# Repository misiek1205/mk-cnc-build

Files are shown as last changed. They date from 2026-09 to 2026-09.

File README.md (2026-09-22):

> **Work in progress / early release.** This build pack is actively developed. Parts, fits, docs, and Bambu projects may change; something may not match your leftover hardware yet. Build at your own risk and expect updates.

# MK CNC — scavenger gantry mill (build pack)

**Work envelope (nominal):** X **299** × Y **271** × Z **100** mm  
**Stack:** printed PLA / PETG / ASA parts + 2020 aluminium extrusion + MGN12 + T8 leadscrews + NEMA steppers (mostly recycled from 3D printers)

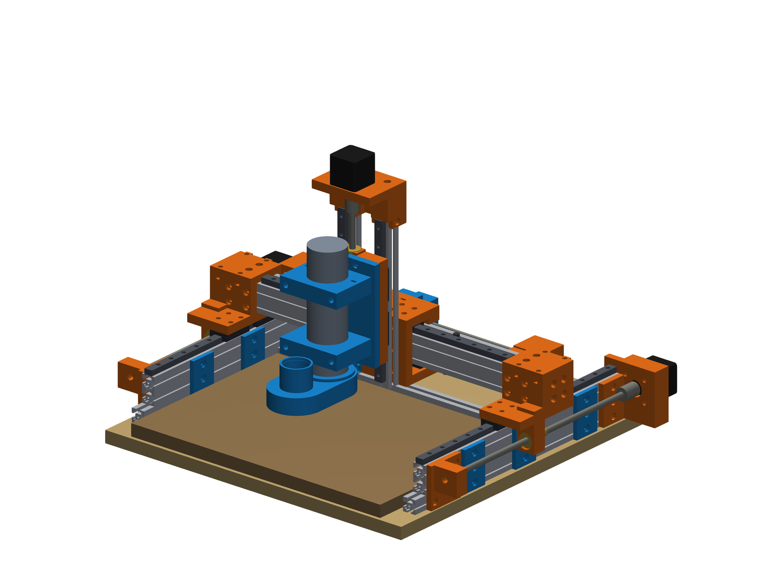
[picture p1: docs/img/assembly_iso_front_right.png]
Front-right isometric


## Important — what this project is (and is not)

This machine was assembled **from leftover parts after various projects**, mainly **retired 3D printers** (rails, steppers, couplers, bearings, extrusion offcuts) plus a small shopping list.

It is **not** claimed to be the stiffest, fastest, or most elegant DIY CNC you can buy or design.  
It **is** a complete, documented way to **build a useful small mill from what you already have on the shelf**, with printable interfaces that make mismatched leftovers fit together.

If you want a purpose-optimised commercial kit or a heavy steel frame, look elsewhere.  
If you want to **turn printer scrap into a mill that can cut wood / soft plastics / light aluminium** (within reason), you are in the right place.

## What you get in this repository

| Path | Contents |
|---|---|
| `stl/` | Printable parts in **print orientation** (English filenames; do not rotate in the slicer) |
| `docs/BOM.md` | Shopping list — what to buy, quantities, approximate EUR costs |
| `docs/PRINTING.md` | Slicer settings, orientations, quantities |
| `docs/ASSEMBLY.md` | Build order, fastener tips, common traps |
| `docs/OVERVIEW.md` | Machine layout + **all** renders |
| `docs/img/` | Assembly and per-part renders |
| `bambu/` | Bambu Studio multi-plate projects: `MK_CNC_P1S.3mf`, `MK_CNC_A1_mini.3mf` |

**Not included:** CadQuery parametric source, Fusion macros, firmware binaries — those stay local / unpublished. This repository is the single public build pack for **builders**.

## Quick specs

- Moving gantry (bridge) on Y; carriage on X; Z on twin 2020 columns
- Rails: MGN12 / MGN12H
- Screws: T8 (X/Y typically 8 mm lead; Z preferably 2 mm lead for self-locking)
- Default tool: ø52 mm 500 W DC spindle (ER11); optional Makita / laser / pen holders in `stl/`
- Operator front = spindle side; model **+X = operator's left** (invert GRBL X if you want joystick intuition)

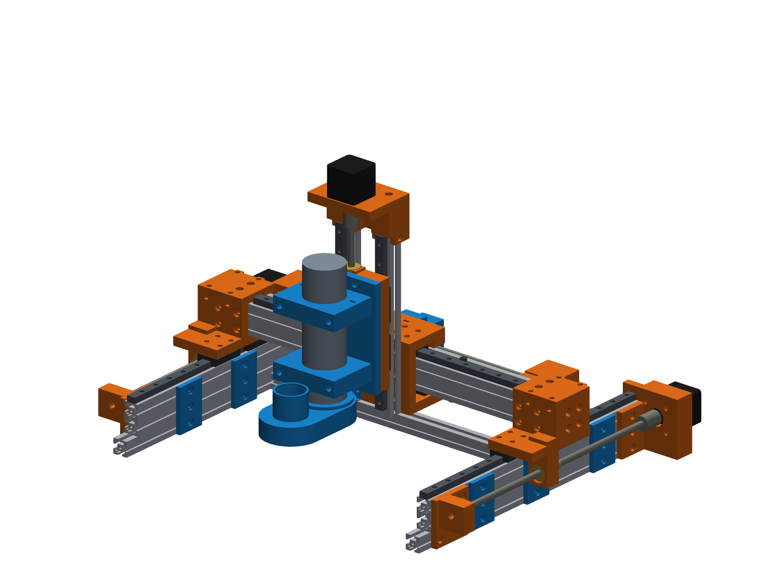
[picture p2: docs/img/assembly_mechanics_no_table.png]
Mechanics without table


## Build flow

1. Read [docs/OVERVIEW.md](docs/OVERVIEW.md) once (layout + all renders).
2. Check [docs/BOM.md](docs/BOM.md) — buy list with quantities and rough costs.
3. Print parts per [docs/PRINTING.md](docs/PRINTING.md).
4. Assemble per [docs/ASSEMBLY.md](docs/ASSEMBLY.md).
5. Wire steppers / limit switches / spindle to your controller (GRBL, FluidNC, …). Controllers are out of scope here.
6. Complete the [commissioning and safety checks](docs/COMMISSIONING.md) before the first powered move.

## Safety

- Eye and ear protection when milling.
- Secure workholding; the plywood/MDF table is sacrificial.
- Spindle and mains PSU are hazardous — if you are not comfortable with mains wiring, get help.
- Printed structural parts in PLA, PETG, or ASA are strong enough (reference machine: Bambu Basic PLA) for this size of machine when printed as specified; they are **not** a substitute for cast iron. Start with wood and plastics; aluminium needs conservative, validated cutting parameters.

## Licence

Hardware documentation and STL files: **CERN-OHL-P-2.0** (see `LICENSE`).  
Renders are part of the documentation set under the same terms.

## Credits

Designed and documented by **misiek1205**.  
Built as a scavenger project — reuse first, buy only what you must.

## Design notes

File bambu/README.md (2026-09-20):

> **WIP:** plate layout may still change as the machine design evolves.

# Bambu Studio print projects

Ready-to-open multi-plate `.3mf` files for the MK CNC printed parts.

| File | Printer | Bed | Plates |
|---|---|-----|---|
| `MK_CNC_P1S.3mf` | Bambu Lab **P1S** (0.4 nozzle) | 256 mm | 6 |
| `MK_CNC_A1_mini.3mf` | Bambu Lab **A1 mini** (0.4 nozzle) | 180 mm | 13 |

## Profile (both)

- Filament: **Bambu PLA Basic** (change to PETG/ASA in Studio if you want)
- Layer height: **0.2 mm**
- Walls: **6**
- Top / bottom: **5**
- Infill: **Adaptive Cubic** ~40% (50% on load-bearing parts: Z plate, X nut, spindle/Makita holders; 30% on laser/pen)
- Supports: **off**
- Orientations match the STL files (do not rotate)

Includes required parts **and** optional Makita / laser / pen holders.

## How to use

1. Open the `.3mf` in **Bambu Studio**.
2. Confirm printer (P1S or A1 mini) and filament.
3. Slice each plate and print (or send the plate you need).
4. First open may ask Studio to refresh thumbnails — that is normal.

If anything looks odd on the bed, use **Auto Arrange** on that plate, then re-slice.

## Note

These projects are generated for MakerWorld / click-to-print. Individual STL files remain in `../stl/` if you prefer to place parts yourself.

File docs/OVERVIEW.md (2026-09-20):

# Machine overview

## Philosophy

MK CNC is a **small moving-gantry mill** whose printed parts adapt scavenged aluminium extrusion, linear rails, leadscrews and steppers into one coherent machine. Dimensions in the BOM match a typical leftover pile from old 3D printers; shorter screws or rails simply reduce travel — the printed parts still fit.

## Layout

- **Base:** plywood plate with 2020 runners and side stacks.
- **Y axis:** gantry (40×40 mm effective beam from 2×2 2020) on MGN12 rails; two T8 screws driven by NEMA17 motors at the rear.
- **X axis:** carriage on dual MGN12 on the beam; one T8 screw behind the beam (motor behind left leg, 608 bearing behind right leg).
- **Z axis:** twin 2020 columns on the carriage front; dual MGN12; T8 in the middle; motor on a printed tower; tool on a universal Z plate.

| Axis | Nominal travel |
|---|---|
| X | ~299 mm |
| Y | ~271 mm |
| Z | ~100 mm |

Largest circular pocket with a ø6 mm endmill in one fixture (reference): about **ø277 mm** (Y-limited).

## Coordinates

- **+Y** = machine front (operator / spindle side)
- **+X** = operator's **left**
- **+Z** = up

If you want GRBL “X+ = right from the operator”, invert the X motor in firmware.

## Naming

`*_L` / `*_R` = **Left / Right from the operator** standing in front of the spindle.  
`L` parts sit on the **+X** side of the model.

## Tool interface

Z plate has a 4× M4 pattern. Swap:

- `spindle_holder_52` — ø52 spindle (default)
- `makita_holder_65` + caps — Makita RT0700 / DRT50 style
- `laser_adapter` — T-slot plate for laser modules
- `pen_holder` — pen / marker clamp
- `dust_shoe_52` - one-piece vacuum dust shoe for the ø52 spindle (clamp slot + 2× M4, upward ø35 hose)

---

## Assembly renders

Front-right isometric

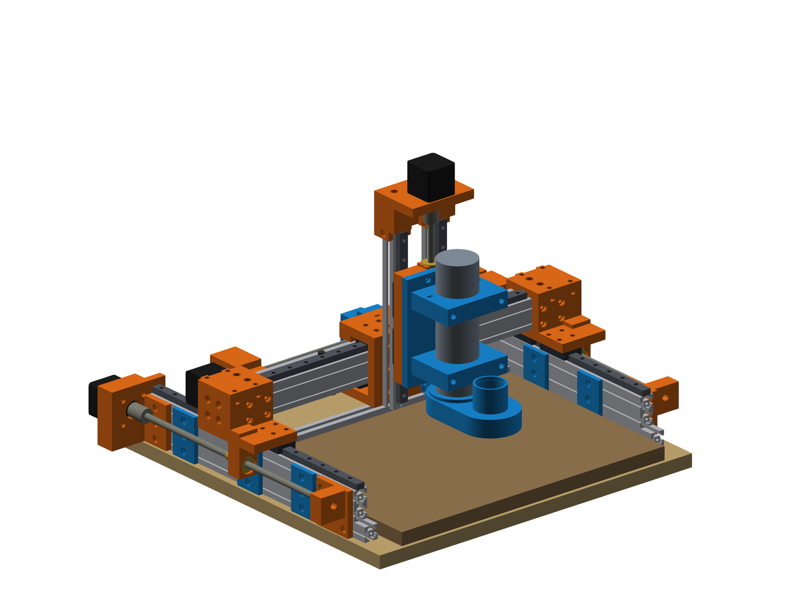
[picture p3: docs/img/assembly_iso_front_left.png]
Front-left isometric


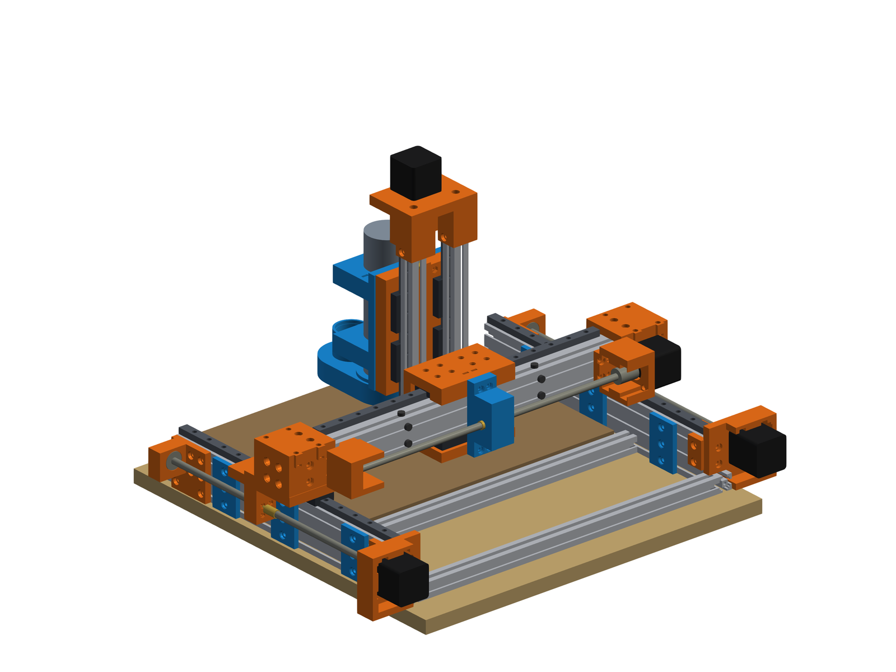
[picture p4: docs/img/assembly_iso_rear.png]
Rear isometric


Mechanics without table

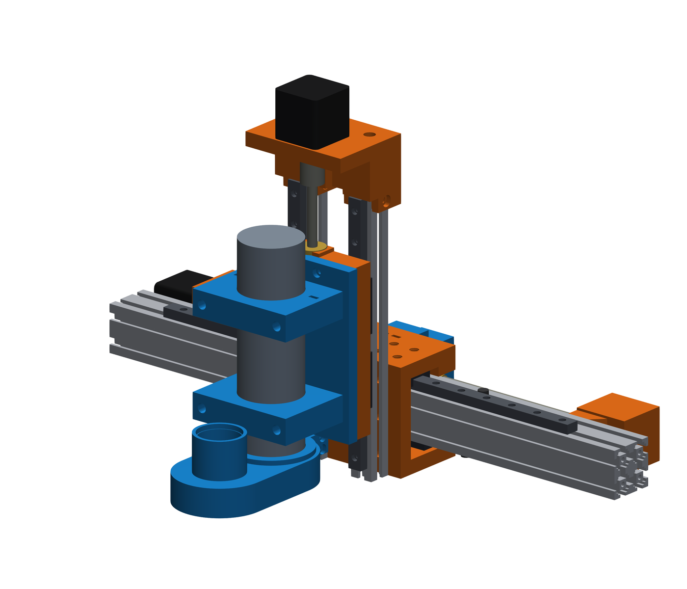
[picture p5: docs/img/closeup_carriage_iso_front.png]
Carriage / Z close-up


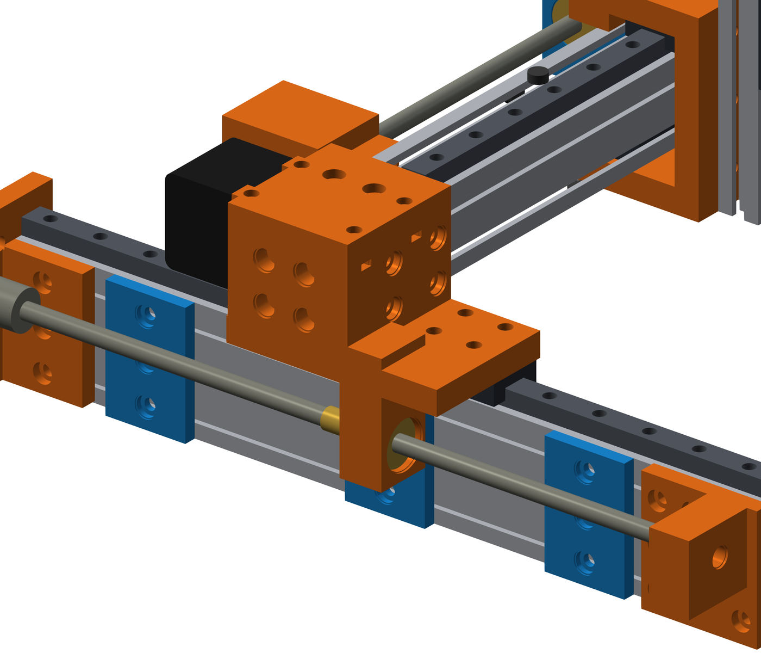
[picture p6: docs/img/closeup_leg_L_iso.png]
Left leg close-up


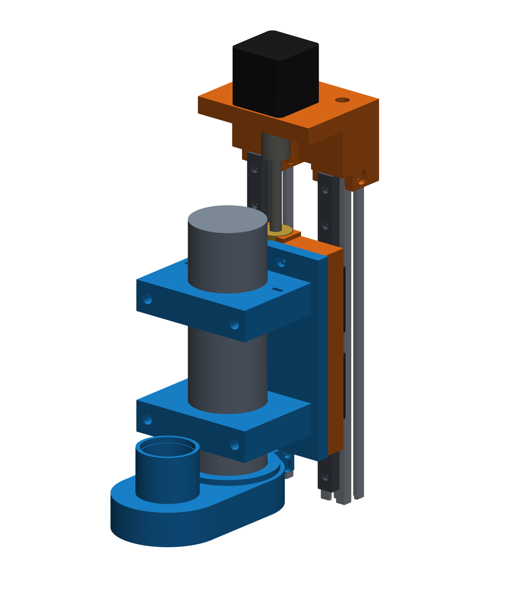
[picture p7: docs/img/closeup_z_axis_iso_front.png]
Z axis close-up


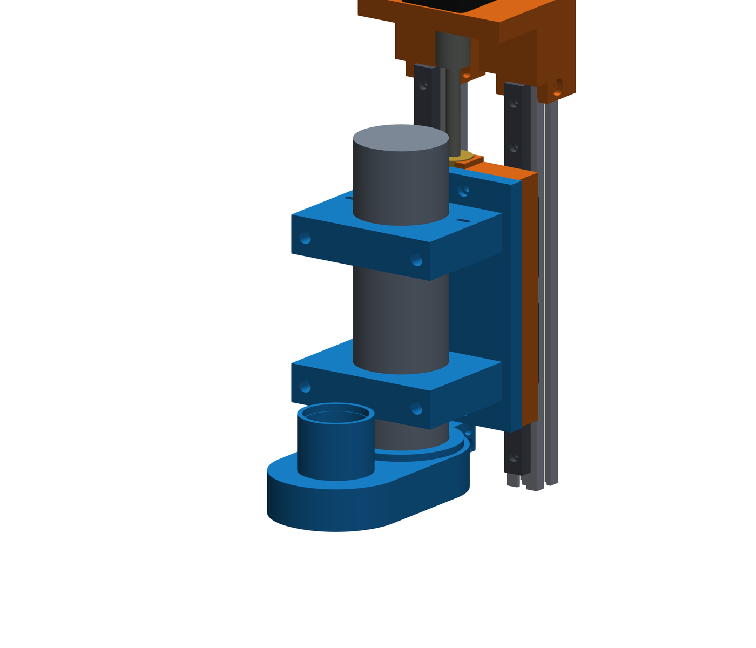
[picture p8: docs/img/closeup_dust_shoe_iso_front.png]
Dust shoe on spindle (front iso)


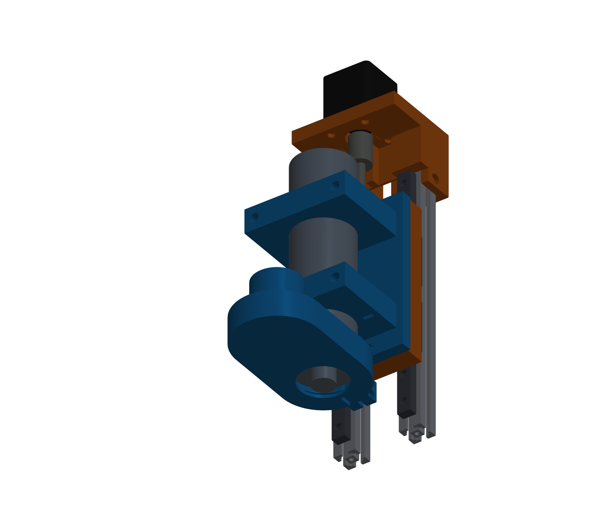
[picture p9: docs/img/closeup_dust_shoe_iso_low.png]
Dust shoe from below


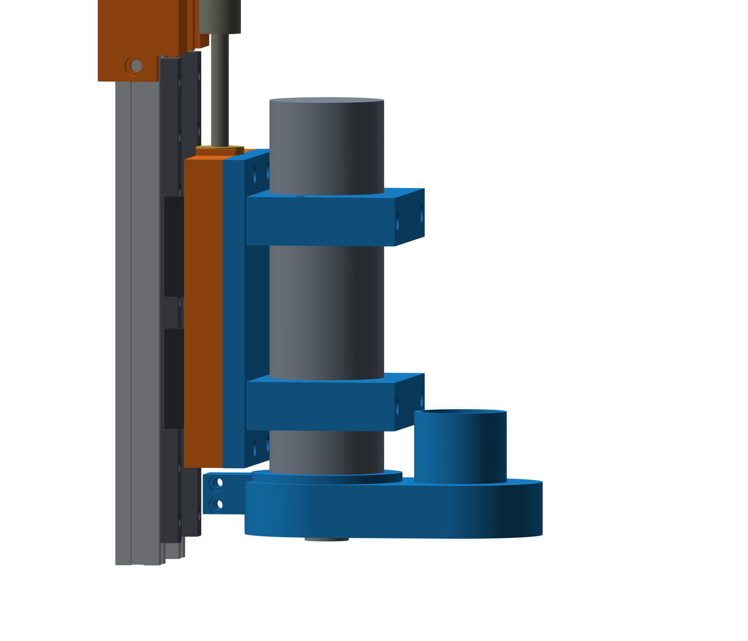
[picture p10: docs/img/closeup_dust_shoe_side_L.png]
Dust shoe side


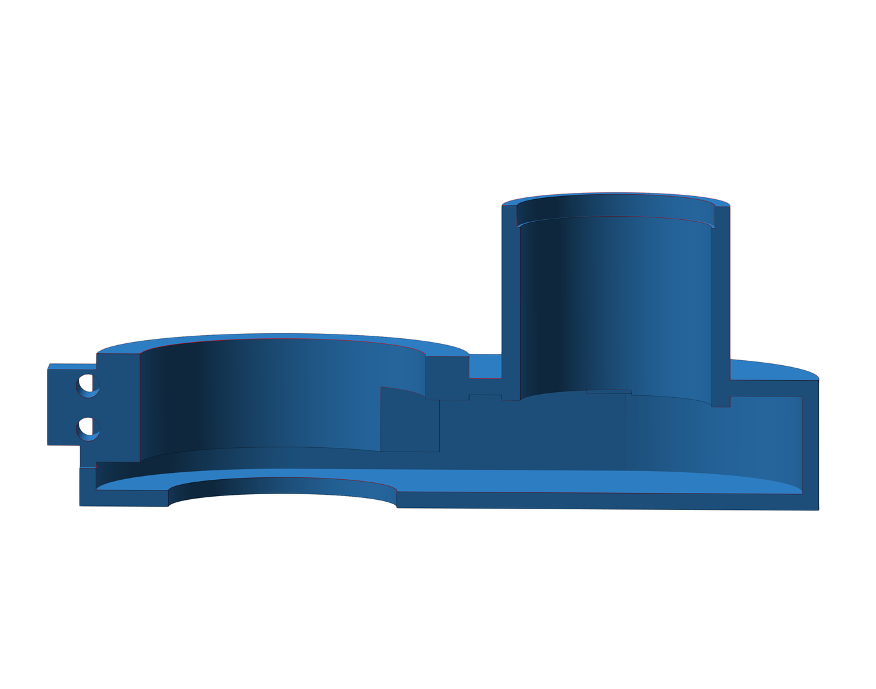
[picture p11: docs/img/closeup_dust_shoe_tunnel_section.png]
Dust shoe section — continuous vacuum tunnel


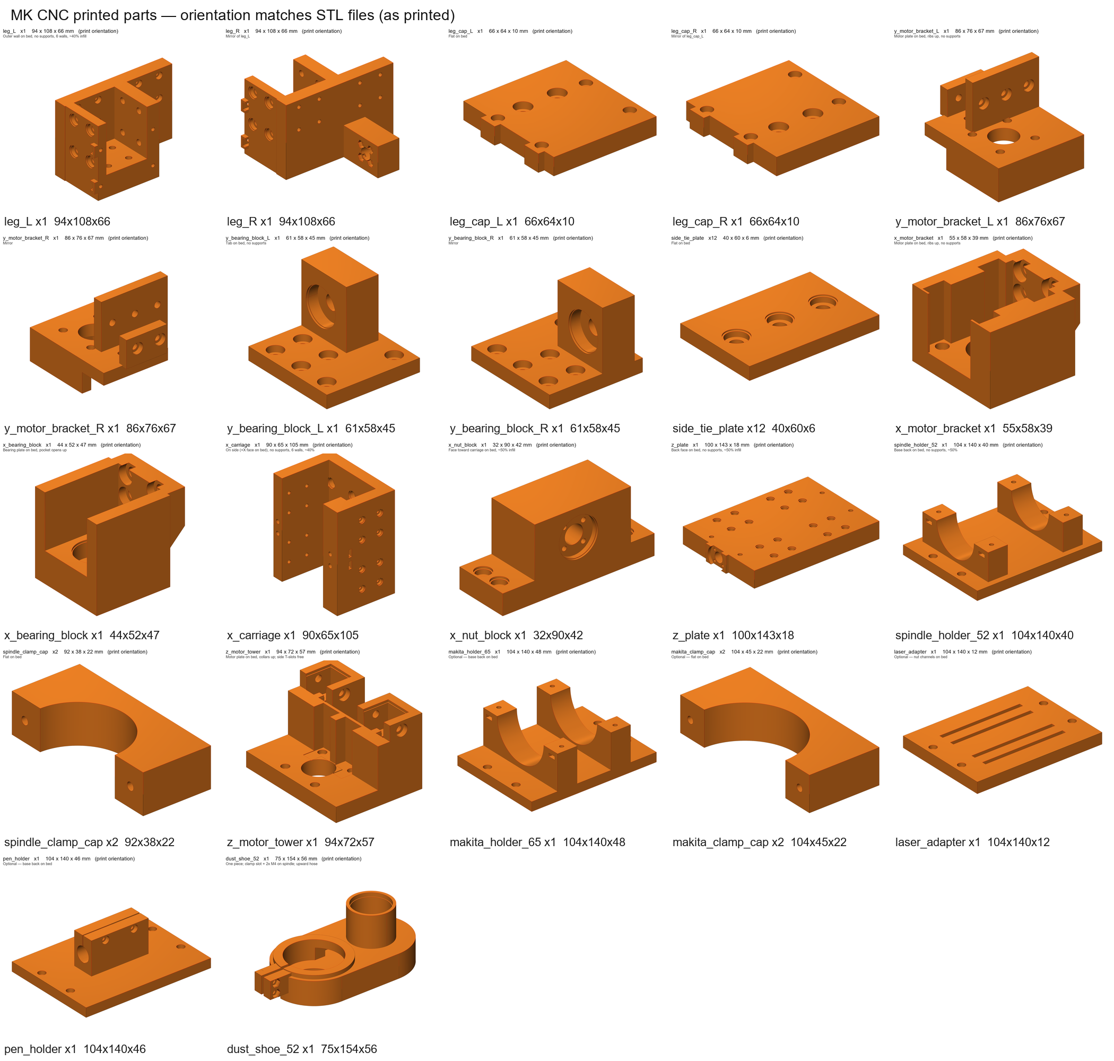
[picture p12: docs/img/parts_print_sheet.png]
Print orientation sheet


---

## Printed parts (previews)

### Structure

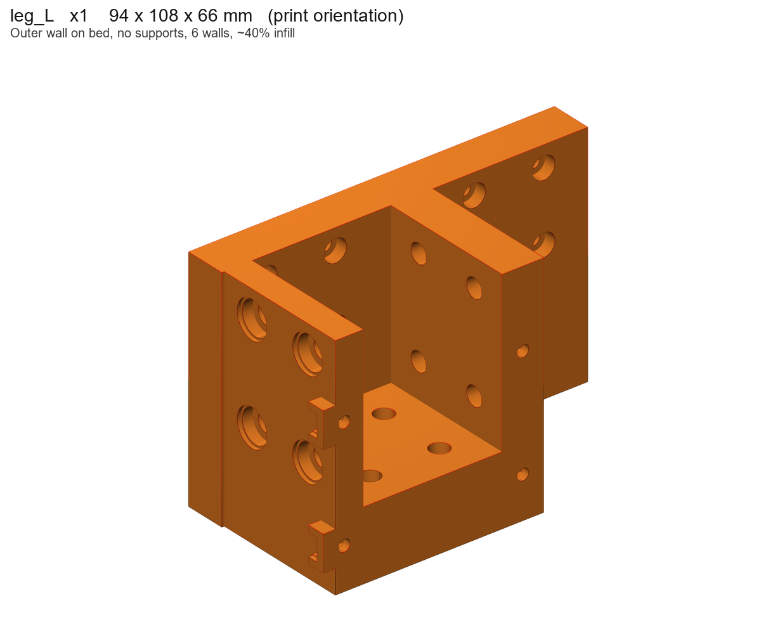
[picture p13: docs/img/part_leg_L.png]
leg_L


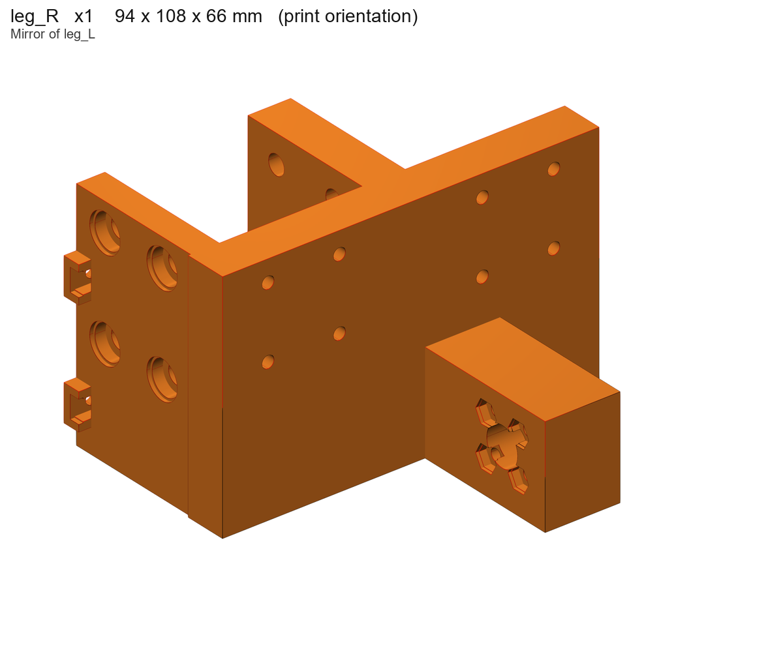
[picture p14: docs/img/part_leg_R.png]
leg_R


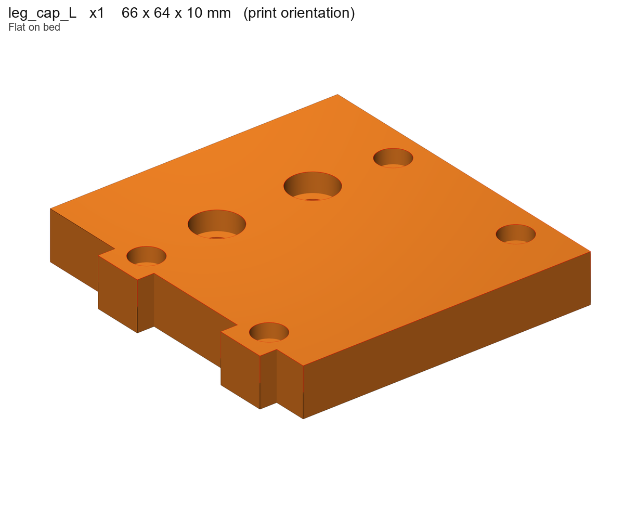
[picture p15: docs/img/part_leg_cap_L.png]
leg_cap_L


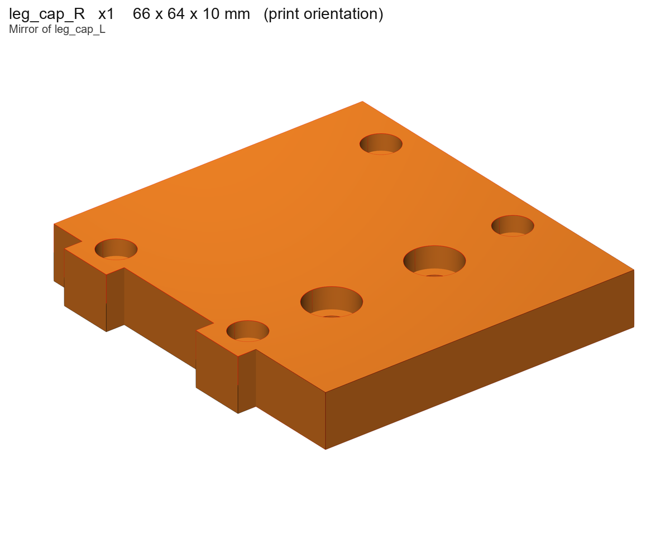
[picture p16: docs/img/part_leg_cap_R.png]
leg_cap_R


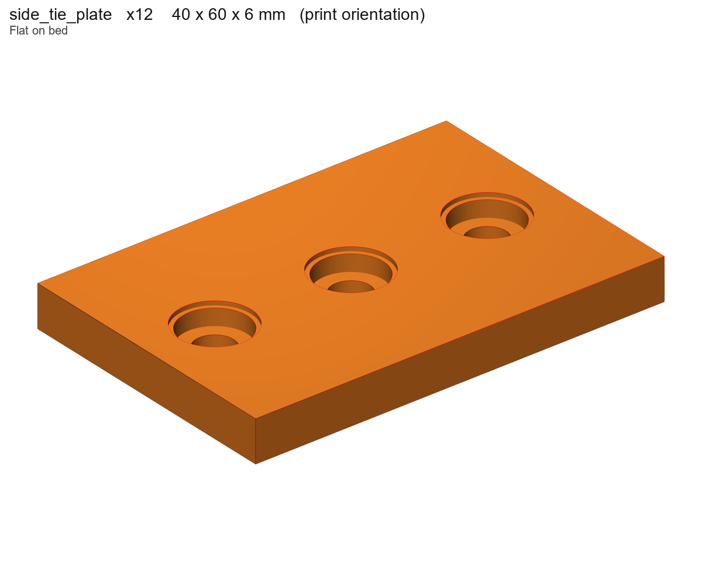
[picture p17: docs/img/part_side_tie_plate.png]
side_tie_plate


### Y axis

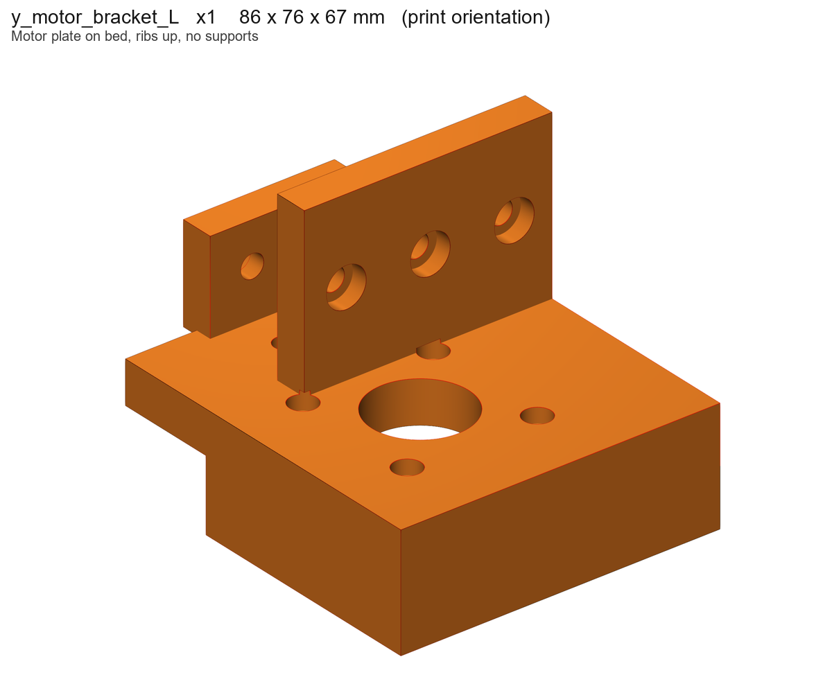
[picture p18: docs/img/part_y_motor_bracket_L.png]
y_motor_bracket_L


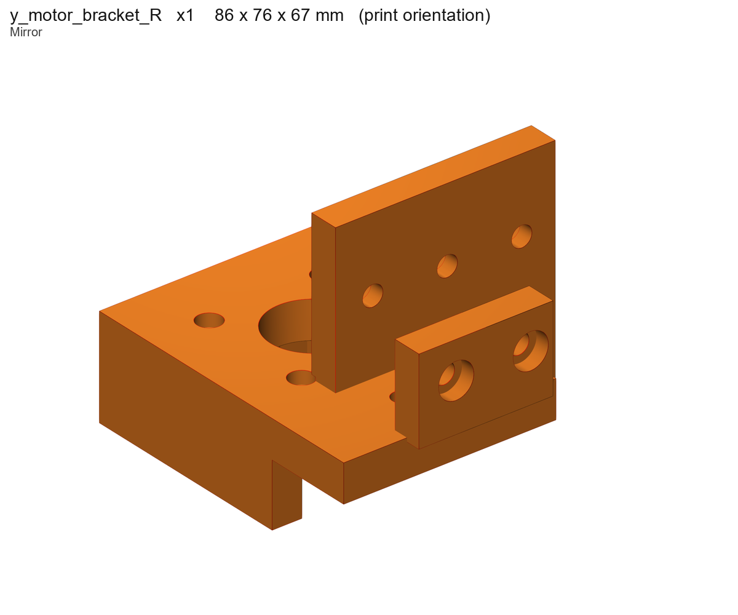
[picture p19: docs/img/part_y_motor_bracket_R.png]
y_motor_bracket_R


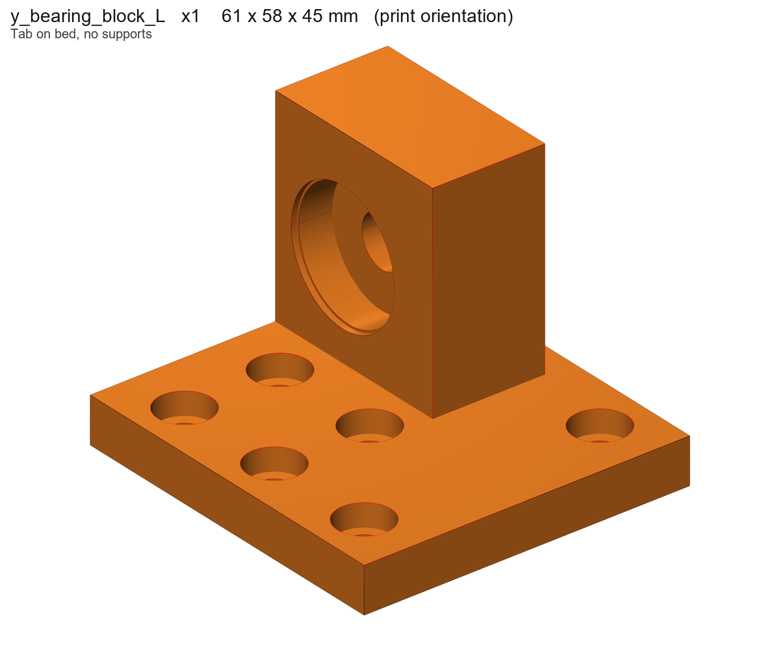
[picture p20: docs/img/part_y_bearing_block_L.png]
y_bearing_block_L


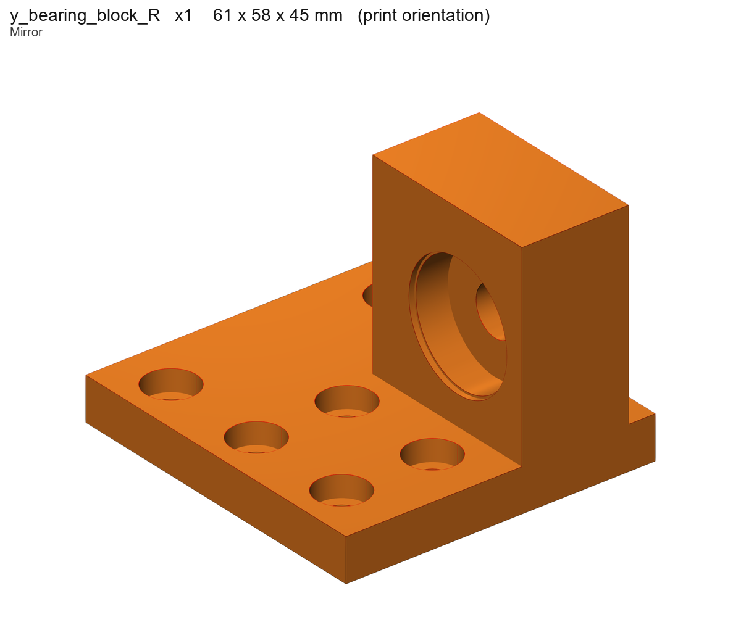
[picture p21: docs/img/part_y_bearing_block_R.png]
y_bearing_block_R


### X axis

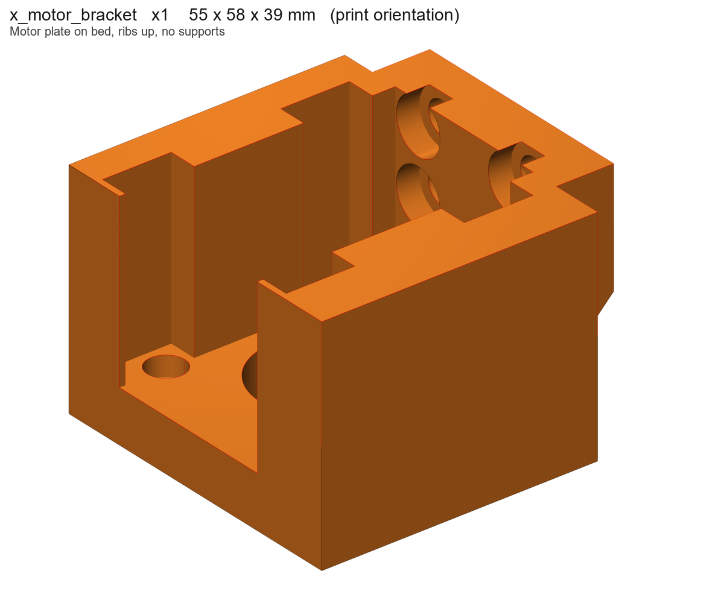
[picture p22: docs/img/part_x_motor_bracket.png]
x_motor_bracket


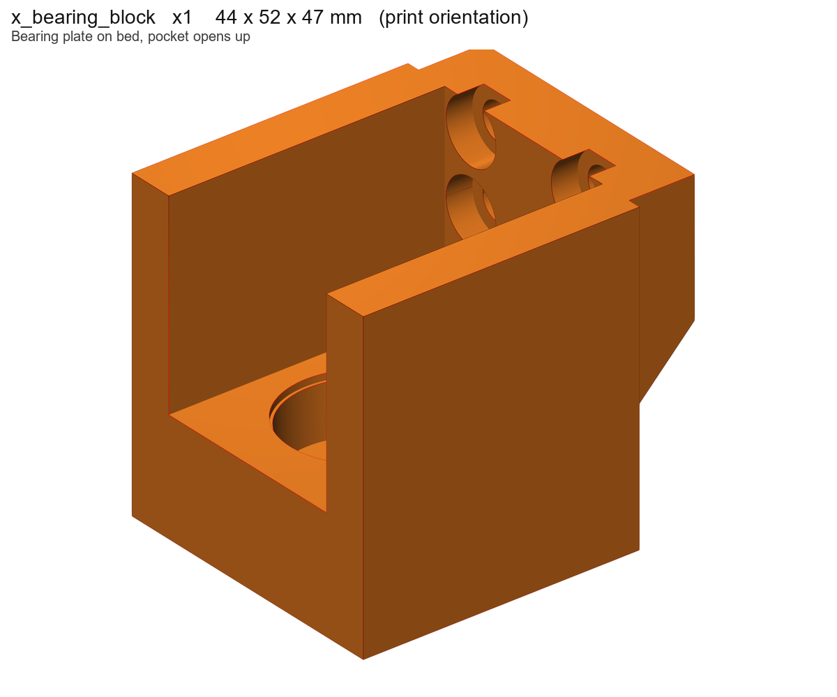
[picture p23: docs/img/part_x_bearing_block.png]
x_bearing_block


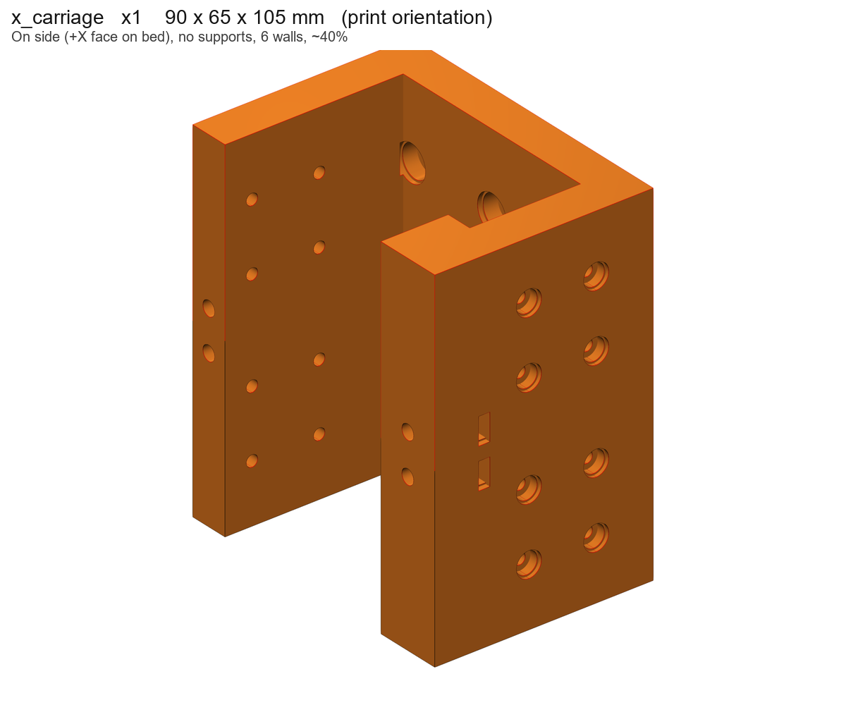
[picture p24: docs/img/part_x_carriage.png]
x_carriage


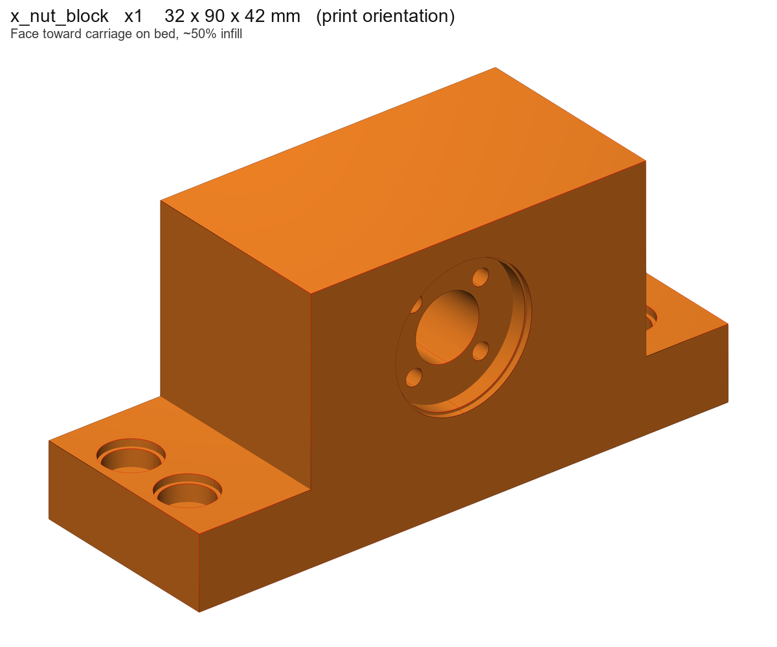
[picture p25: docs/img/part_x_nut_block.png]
x_nut_block


### Z axis / tools

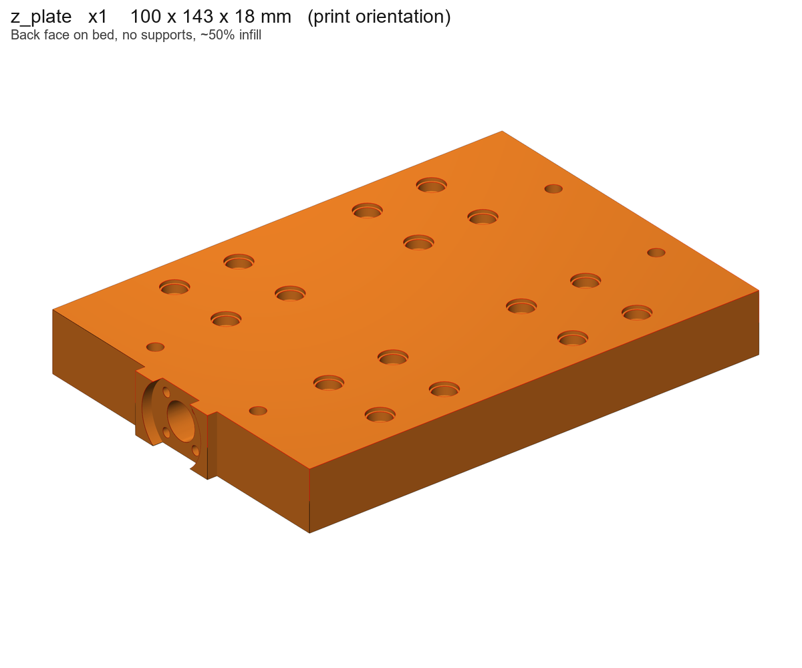
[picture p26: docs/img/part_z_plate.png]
z_plate


z_motor_tower

spindle_holder_52

spindle_clamp_cap

makita_holder_65

makita_clamp_cap

laser_adapter

pen_holder

dust_shoe_52

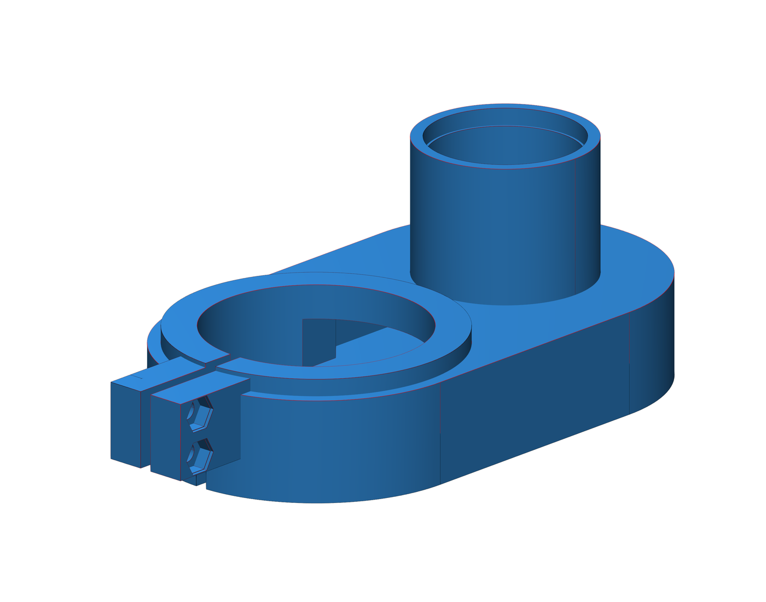
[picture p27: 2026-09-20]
docs/img/closeup_dust_shoe_clamp_iso.png

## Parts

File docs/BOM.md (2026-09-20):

# Bill of materials — shopping list

Simple buy list for the **reference** machine (X travel ~299 mm, Y ~271 mm, Z ~100 mm).

**Prices** are approximate **AliExpress / China marketplace** ballparks in **EUR**, mid-2026, shipping excluded. Local EU shops are often 1.5–3× higher. Treat costs as a guide, not a quote.

## Reference geometry

These are the cut lengths for the documented reference machine. Measure cut
length from end to end; they are not the nominal work travel.

| Component | Qty | Length | Notes |
|---|----:|---:|---|
| 2020 bridge beam | 4 | 500 mm | 2×2 2020 beam |
| 2020 runners / crossbars | 4 | 420 mm | Base members |
| 2020 sides | 4 | 380 mm | Side stacks |
| 2020 Z columns | 2 | 240 mm | Carriage to Z tower |
| MGN12 X rail | 2 | 400 mm | With MGN12H carriages |
| MGN12 Y rail | 2 | 380 mm | |
| MGN12 Z rail | 2 | 220 mm | Often cut from 350 mm rails |
| T8 X screw | 1 | 400 mm | 8 mm lead typical |
| T8 Y screw | 2 | 350 mm | 8 mm lead typical |
| T8 Z screw | 1 | 200 mm | Prefer 2 mm lead for self-locking |

Shorter rails or screws can be used if they fit the printed interfaces, but
they reduce the stated travel and must be checked for end-of-travel collisions.

## 1. Buy this (mechanics)

| # | What to buy | Qty | ~EUR each | ~EUR total | Notes |
|---|---|-----|---|---|---|
| 1 | MGN12 rail **400 mm with MGN12H carriage** | 2 | 14 | 28 | X axis |
| 2 | MGN12H carriage (loose) | 3 | 5 | 15 | Need **12** carriages total (4Y+4X+4Z); buy the rest if your scrap pile is short |
| 3 | T8 leadscrew **400 mm** + anti-backlash nut | 1 | 8 | 8 | X; 8 mm lead typical |
| 4 | T8 leadscrew **350 mm** + anti-backlash nut | 2 | 7 | 14 | Y |
| 5 | T8×**2 mm** leadscrew ~**200 mm** + anti-backlash nut | 1 | 8 | 8 | Z; 2 mm lead preferred (self-locking) |
| 6 | 608-2RS ball bearing | 3 | 1 | 3 | Only if you do not already have them |
| 7 | Flexible coupler 5×8 mm | 4 | 2 | 8 | Only if missing from old printers |
| 8 | M5 T-nuts for 2020 | ~120 | — | 8 | Bulk bag |
| 9 | M3 T-nuts for 2020 | ~100 | — | 6 | Bulk bag |
| 10 | Assorted screws (M3 / M4 / M5) + hex nuts | 1 kit | — | 15 | See fastener table below if you buy individually |
| | **Subtotal mechanics (typical)** | | | **~€110** | Assumes you still need most carriages/couplers |

If you already have rails, screws, steppers and T-nuts from old printers, the **extra buy** is often only items 1–5 → roughly **~€60–80**.

## 2. Buy this (tool + sheet goods)

| # | What to buy | Qty | ~EUR | Notes |
|---|---|-----|---|---|
| 11 | DC spindle ~500 W, body **ø52**, ER11 + matching PSU | 1 | 50–80 | Skip if you reuse another tool |
| 12 | Plywood 18 mm, ~480 × 500 mm | 1 | 15–25 | Base plate (local timber yard) |
| 13 | MDF 18 mm, ~404 × 287 mm | 1 | 8–15 | Sacrificial table |
| 14 | M6 wood inserts (table grid) | ~12 | 3 | Optional fixture grid |

## 3. Usually scavenged (check your shelf first)

Do **not** buy these if you already have them from old 3D printers:

| Item | Qty needed | Typical source |
|---|---|---|
| 2020 aluminium extrusion (cut to length) | sides, 2×2 beam, Z columns, crossbars | printer frames / leftover stock |
| MGN12 rails (Y / Z) | 2×380 mm / 2×220 mm | old printers; see reference geometry above |
| NEMA17 steppers | 4 | old printers |
| 5×8 couplers, 608 bearings | 4 + 3 | old printers |
| M3 / M5 T-nuts and screws | see below | leftover bags |

## 4. Anti-backlash nuts (important)

Buy the common brass spring T8 nuts:

- mounting flange **ø22**
- 4× M3 on ~16 mm PCD
- spring + small retainer on the outside

**Mount:** flange flat on the printed part, spring stack **outside** the plastic. The hole only needs to clear the leadscrew.

## 5. Fastener counts (if buying loose)

Approximate, buy **+10%** spare:

| Use | Screw | Qty |
|-----|---|-----|
| Y / X / Z rails | M3×8 | ~80 |
| Carriages → legs / X carriage | M3×16 | 32 |
| Carriages → Z plate | M3×20 | 16 |
| Y anti-backlash nuts | M3×25 | 8 |
| X / Z anti-backlash nuts | M3×12 | 8 |
| Y motors | M3×16 | 8 |
| X / Z motors | M3×10 / M3×16 | 4 + 4 |
| Legs ↔ beam | M5×16 / M5×30 | 8 + 8 |
| Leg caps | M5×16 + M3×16 | 4 + 8 |
| Tool → Z plate | M4×25 (laser: M4×30) | 4 |
| Beam clamp (2×2) | M5×30 | 12 |
| Y motor / bearing / side ties / brackets | M5×12 / M5×16 / M5×20 | ~70 |
| X nut block → carriage | M4×30 | 4 |
| Z columns / tower / spindle clamps | M5×16 / M5×40 / M4×40 | 6 + 2 + 4 |

## 6. Optional tools (print parts already in `stl/`)

| Tool | Extra buy | STL |
|---|---|-----|
| Makita RT0700 / DRT50 style (ø65) | router if you do not own one | `makita_holder_65` + caps |
| Laser module | module + PSU | `laser_adapter` |
| Pen / marker | — | `pen_holder` |
| Dust shoe for ø52 spindle | Hose ~ø35 ID, upward port; clamp slot + 2× M4 | `dust_shoe_52` (qty 1) |

## Ballpark totals

| Scenario | ~EUR |
|---|---|
| You have extrusion, steppers, many T-nuts; buy rails/screws/carriages only | **60–80** |
| Full mechanics buy (little scrap) | **~110** |
| + spindle + sheet goods | **+70–120** |
| **Complete kit from almost nothing** | **~180–230** |

Controller, endstops, wire and PSU for steppers are **not** listed — pick your own (GRBL, FluidNC, etc.).

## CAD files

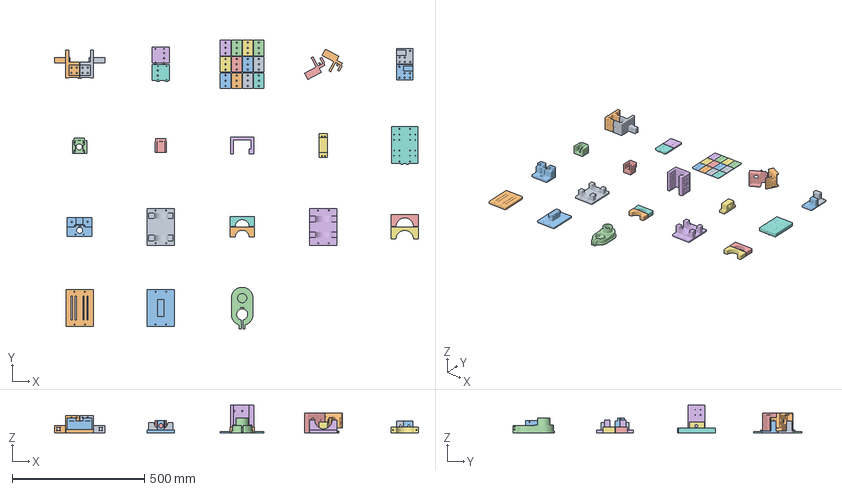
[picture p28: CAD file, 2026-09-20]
bambu/MK_CNC_P1S.3mf
1375.8 x 1092.5 x 105.0 mm
leg_R.stl
laser_adapter.stl
pen_holder.stl
dust_shoe_52.stl
makita_clamp_cap_1.stl
makita_holder_65.stl
makita_clamp_cap_2.stl
spindle_clamp_cap_1.stl
spindle_holder_52.stl
spindle_clamp_cap_2.stl
z_motor_tower.stl
x_motor_bracket.stl
x_bearing_block.stl
x_carriage.stl
x_nut_block.stl
z_plate.stl
y_bearing_block_L.stl
y_motor_bracket_L.stl
y_bearing_block_R.stl
side_tie_plate_1.stl
y_motor_bracket_R.stl
leg_cap_R.stl
side_tie_plate_2.stl
leg_cap_L.stl
side_tie_plate_3.stl
leg_L.stl
side_tie_plate_4.stl
side_tie_plate_5.stl
side_tie_plate_6.stl
side_tie_plate_7.stl
side_tie_plate_8.stl
side_tie_plate_9.stl
side_tie_plate_10.stl
side_tie_plate_11.stl
side_tie_plate_12.stl

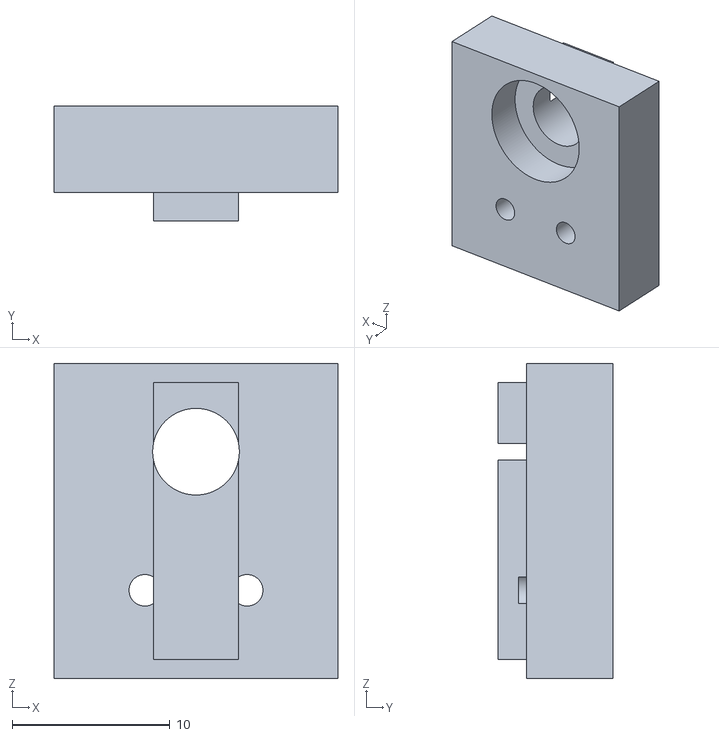
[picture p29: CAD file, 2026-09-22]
stl/endstop_mount_2020.stl
18.0 x 7.30 x 20.0

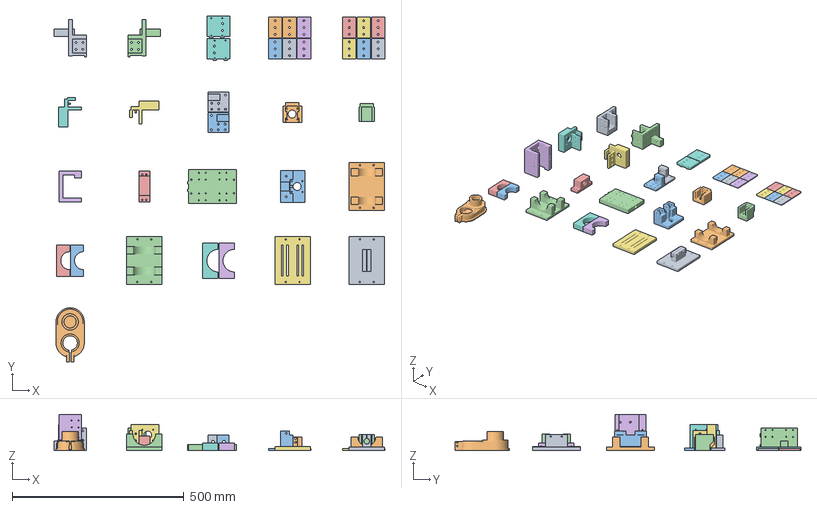
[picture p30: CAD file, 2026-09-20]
bambu/MK_CNC_A1_mini.3mf
964.0 x 1007.4 x 105.0 mm
leg_L.stl
dust_shoe_52.stl
spindle_clamp_cap_1.stl
makita_holder_65.stl
spindle_clamp_cap_2.stl
makita_clamp_cap_1.stl
laser_adapter.stl
makita_clamp_cap_2.stl
pen_holder.stl
spindle_holder_52.stl
z_motor_tower.stl
z_plate.stl
x_nut_block.stl
x_carriage.stl
y_motor_bracket_R.stl
y_motor_bracket_L.stl
y_bearing_block_L.stl
x_motor_bracket.stl
y_bearing_block_R.stl
x_bearing_block.stl
side_tie_plate_7.stl
side_tie_plate_1.stl
side_tie_plate_8.stl
leg_cap_R.stl
side_tie_plate_9.stl
side_tie_plate_2.stl
side_tie_plate_10.stl
leg_R.stl
side_tie_plate_11.stl
side_tie_plate_3.stl
side_tie_plate_12.stl
leg_cap_L.stl
side_tie_plate_4.stl
side_tie_plate_5.stl
side_tie_plate_6.stl

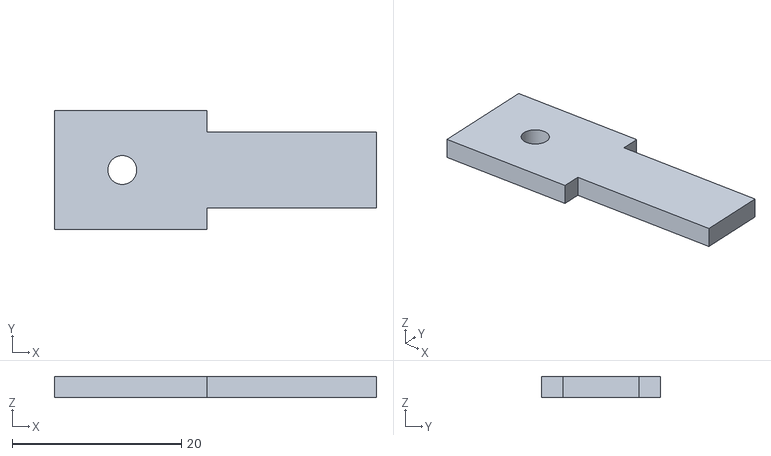
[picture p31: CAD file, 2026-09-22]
stl/endstop_flag.stl
38.0 x 14.0 x 2.50

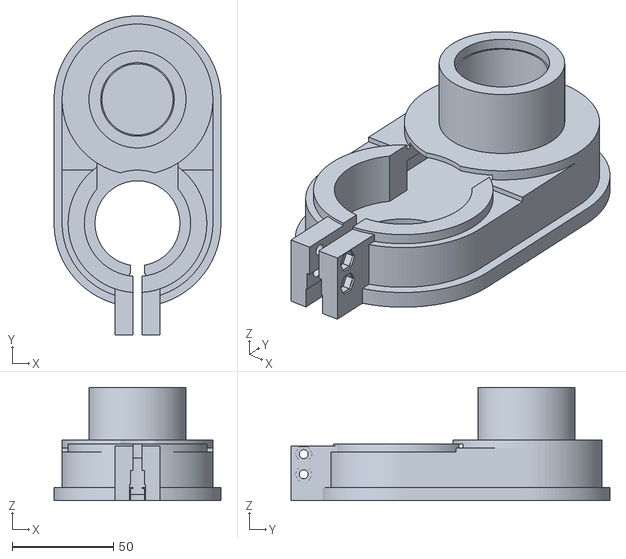
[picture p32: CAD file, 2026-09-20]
stl/dust_shoe_52.stl
82.6 x 157.9 x 56.0

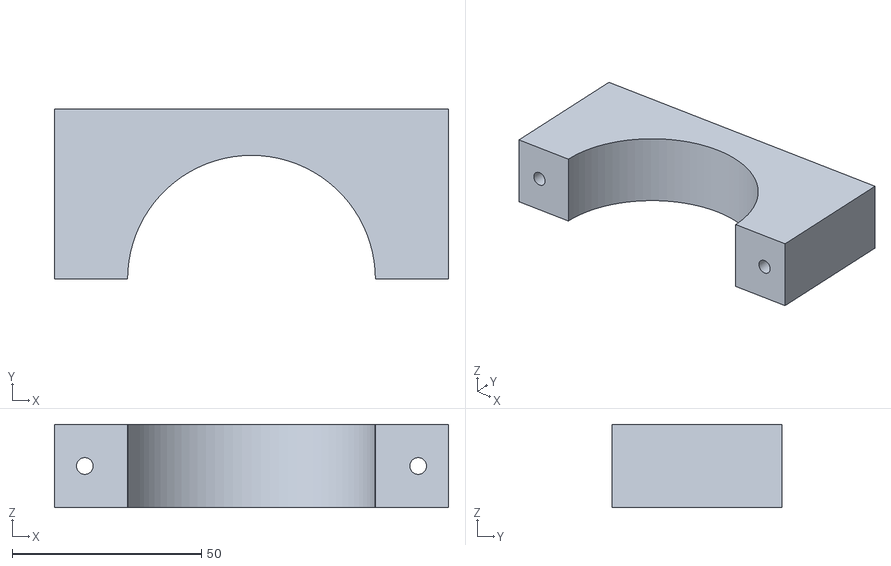
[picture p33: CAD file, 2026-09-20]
stl/makita_clamp_cap.stl
104.0 x 45.0 x 22.0

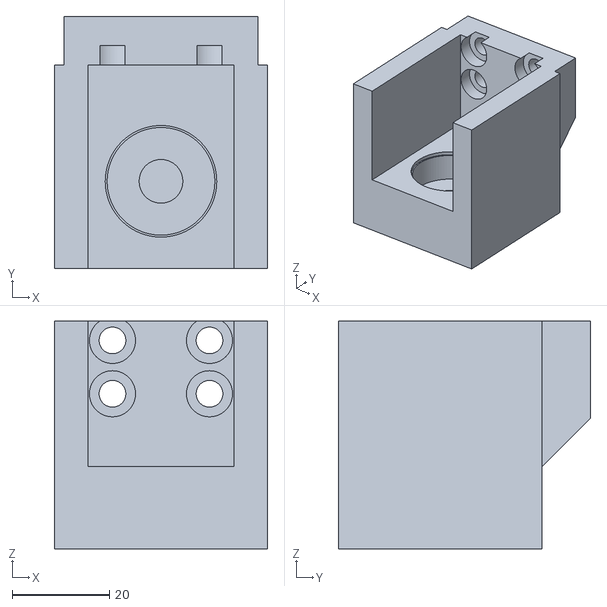
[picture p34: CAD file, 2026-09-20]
stl/x_bearing_block.stl
44.0 x 52.0 x 47.0

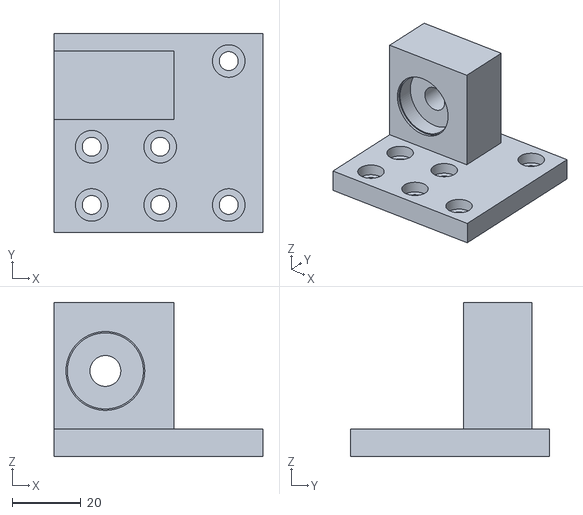
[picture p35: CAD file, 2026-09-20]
stl/y_bearing_block_L.stl
61.0 x 58.0 x 45.0

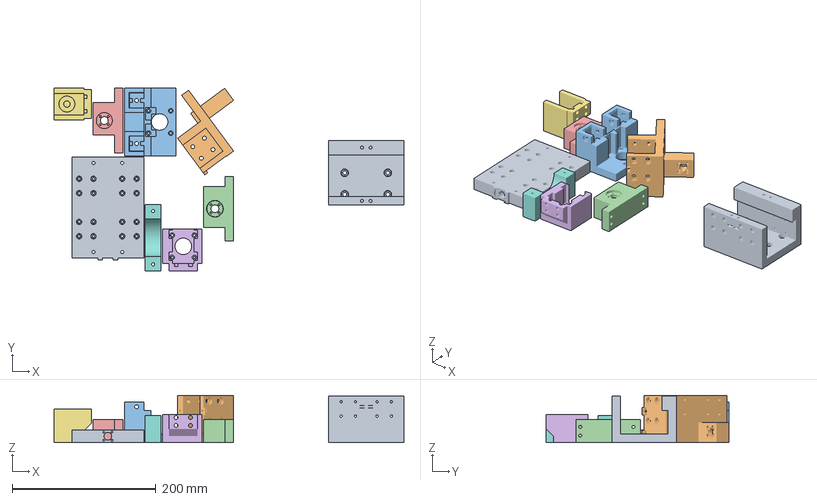
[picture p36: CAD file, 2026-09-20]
stl/laser_adapter.3mf
487.0 x 254.0 x 66.0 mm
karetka_X.stl
noga_P.stl
wieza_silnika_Z.stl
blok_nakretki_X.stl x 2
wspornik_silnika_X.stl
blok_lozyska_X.stl
nakladka_wrzeciona.stl
plyta_Z.stl

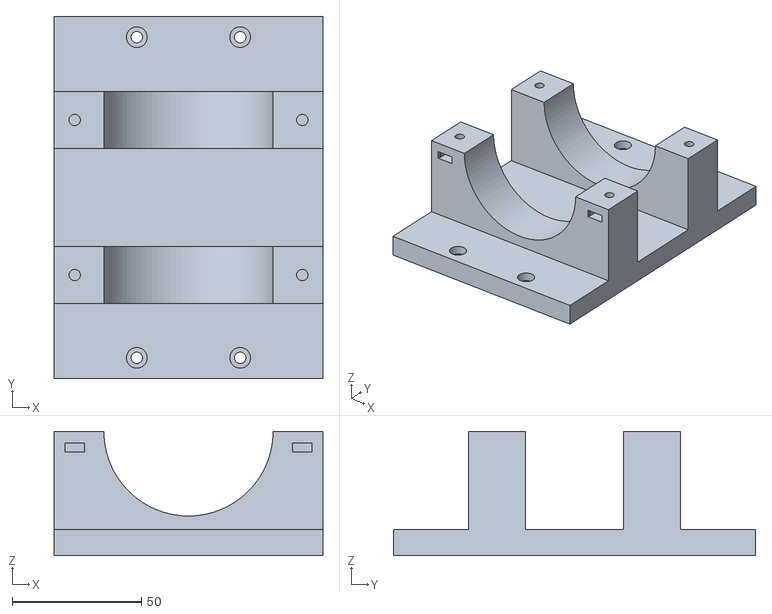
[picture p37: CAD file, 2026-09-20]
stl/makita_holder_65.stl
104.0 x 140.0 x 48.0

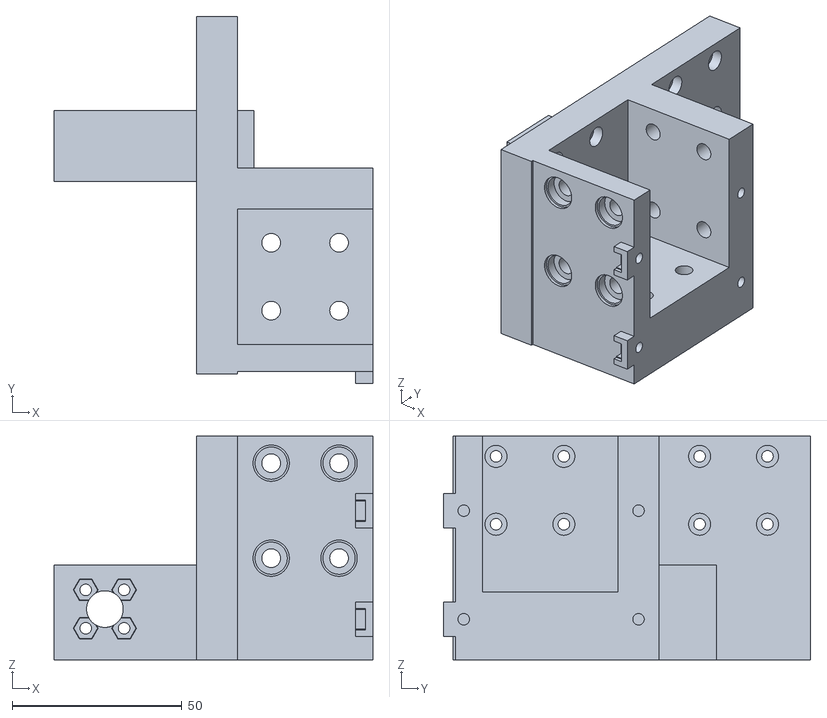
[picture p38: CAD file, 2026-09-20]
stl/leg_L.stl
94.0 x 108.2 x 66.0

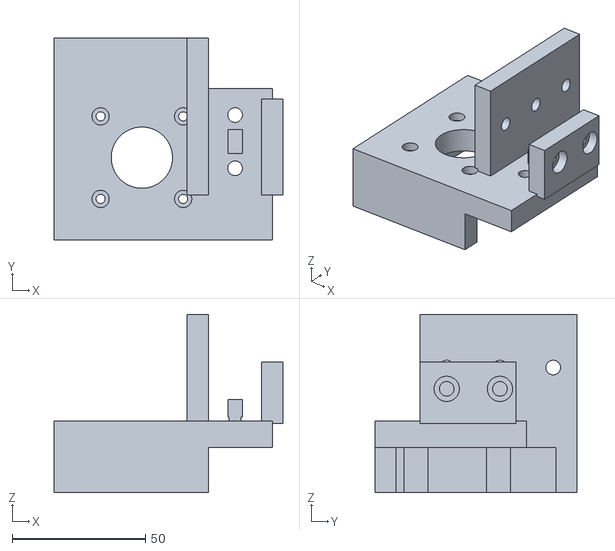
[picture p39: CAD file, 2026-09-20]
stl/y_motor_bracket_R.stl
86.0 x 76.0 x 67.0

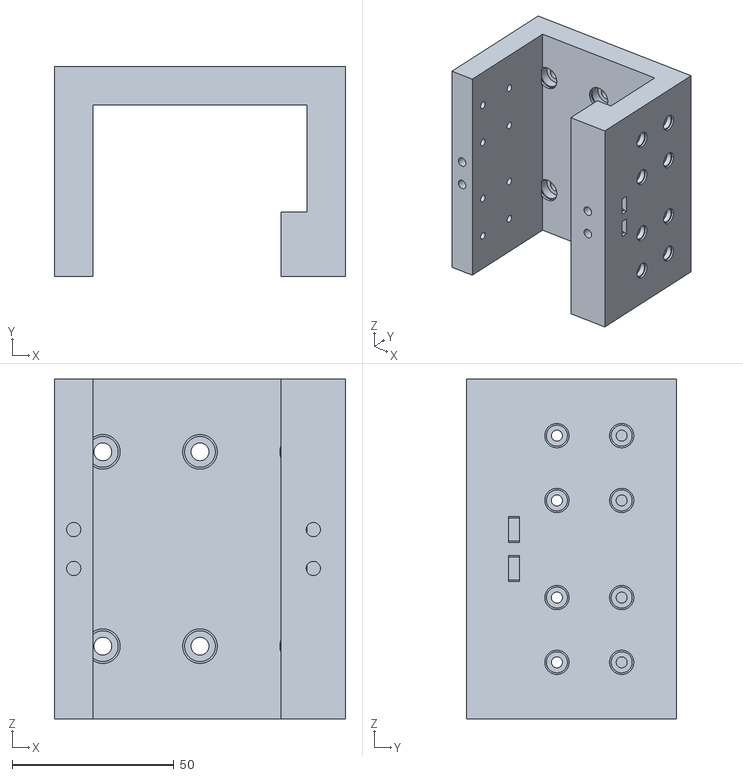
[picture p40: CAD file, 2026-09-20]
stl/x_carriage.stl
90.0 x 65.0 x 105.0

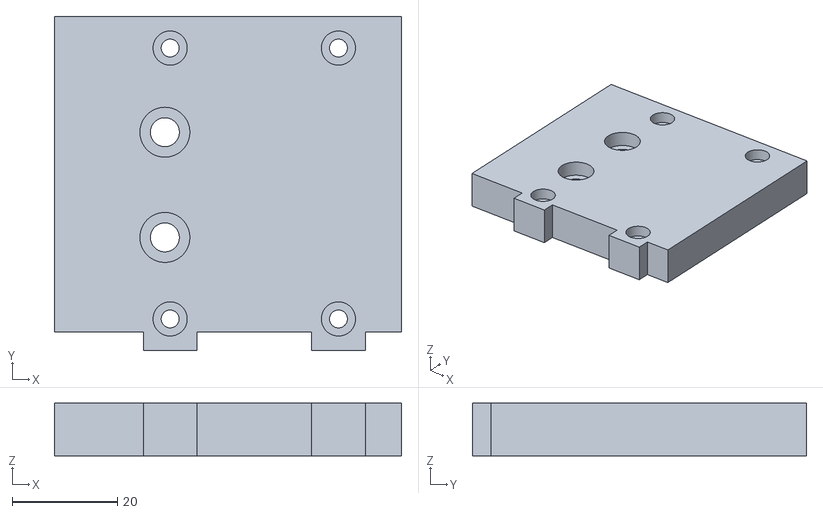
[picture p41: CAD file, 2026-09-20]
stl/leg_cap_L.stl
66.0 x 63.5 x 10.0

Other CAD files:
stl/leg_R.stl
stl/spindle_clamp_cap.stl
stl/pen_holder.stl
stl/z_motor_tower.stl
stl/laser_adapter.stl
stl/leg_cap_R.stl
stl/side_tie_plate.stl
stl/spindle_holder_52.stl
stl/x_motor_bracket.stl
stl/x_nut_block.stl
stl/y_bearing_block_R.stl
stl/y_motor_bracket_L.stl
stl/z_plate.stl

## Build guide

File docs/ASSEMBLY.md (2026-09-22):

# Assembly guide

Coordinates match [OVERVIEW.md](OVERVIEW.md). Measure profile hole positions **from the end of each extrusion**.

Read the **trap list** at the end before you torque everything down.

## 1. Print

See [PRINTING.md](PRINTING.md). Dry-fit: 608 bearings push in by hand; `x_nut_block` width matches the carriage; `z_motor_tower` collars slide onto column tops.

## 2. Cut and tap aluminium

- Cut the reference-machine 2020 profiles to length:

  | Element | Qty | Cut length |
  |---------|----:|-----------:|
  | Bridge beam (2×2 2020) | 4 | 500 mm |
  | Runners / crossbars | 4 | 420 mm |
  | Sides | 4 | 380 mm |
  | Z columns | 2 | 240 mm |

  The matching reference rails are X 2×400 mm, Y 2×380 mm and Z 2×220 mm;
  the screws are X 400 mm, Y 2×350 mm and Z 200 mm. See
  [BOM.md](BOM.md#reference-geometry) for the complete reference geometry.
- Tap centre holes M5 where screws go into the profile core (leg end walls, Z tower tops).
- Drill ø5.5 through the beam stack for the 12 clamp bolts (slide-in T-nuts).

## 3. Base and sides

1. Build left/right side stacks (extrusion + `side_tie_plate` ×12).
2. Mount Y rails; leave one rail slightly loose until the gantry walks true, then tighten hole-by-hole.
3. Fit `y_motor_bracket_L` / `_R` at the rear — T-nuts in the inner slots **before** you lose access.
4. Fit `y_bearing_block_L` / `_R` at the front.

## 4. Legs and gantry beam

1. Assemble the 2×2 beam: insert **12× M5 T-nuts** into the inner slots **before** you close the stack.
2. Seat `leg_L` / `leg_R` on the Y carriages; clamp the beam into the leg pockets.
3. Add `leg_cap_L` / `_R`: slide captive M3 nuts into the slots first, then cap screws.
4. Mount Y anti-backlash nuts on the leg arms: **ø22 flange flat on the print**, spring outside.

## 5. X drive and carriage

1. Mount `x_motor_bracket` (behind left leg) and `x_bearing_block` (behind right leg) on the rear face of the beam.
2. Install X screw, coupler, 608 bearing.
3. Slide `x_carriage` onto the X rails; square the rails (one tight, one loose, walk the carriage).
4. Fit `x_nut_block` to the carriage rear; nut flange flat against the block, spring outside.
5. Insert column T-nuts into the carriage front pockets **before** bolting Z columns.

## 6. Z axis

1. Bolt Z columns to the carriage; mount Z rails and carriages.
2. Fit `z_plate`; insert M4 hex nuts into the rear pockets.
3. Mount Z anti-backlash nut on top of the plate (spring in free air).
4. Slide `z_motor_tower` onto the column tops: **tenons only in front/rear slots**; install side M5 T-nuts **before** dropping the tower.
5. Motor M3 from **below** the tower plate; rear pair via the access ovals between the columns.
6. Attach `spindle_holder_52` (or another tool) to the Z interface.

## 7. Table and electrics

- Fit plywood base and MDF table so Z can reach the surface.
- Wire steppers, endstops and spindle PSU to your controller. Firmware is out of scope of this pack.
- Before powering the spindle, complete [COMMISSIONING.md](COMMISSIONING.md). In particular, the two Y motors require independent homing against separate Y switches so the gantry is squared at every homing cycle.

## Assembly traps

1. **T-nuts before you block access** — beam stack, carriage column pockets, Z tower side slots, laser adapter channels.
2. **Rail parallelization** — never torque both rails fully before walking a carriage/plate.
3. **Do not rotate STLs** — legs and carriage print on their side for a reason.
4. **608 bearings** — finger press; lead-ins are in the STLs; no hammer.
5. **Anti-backlash nuts** — flat ø22 on plastic, spring outside; only the screw goes through the hole.
6. **L/R mirrors** — check pocket / nut-arm handedness before printing a second side.
7. **Z motor screws** from below; start threads before fully seating the coupler if the oval is tight.

## Closest images

- Legs: `img/closeup_leg_L_iso.png`
- Carriage / Z: `img/closeup_carriage_iso_front.png`
- Full machine: `img/assembly_iso_front_right.png`

## Optional: dust shoe (ø52 spindle)

One-piece stadium/capsule shoe with a **clamp slot** on the spindle and a single **upward** ~ø35 vacuum port:

1. Print `dust_shoe_52` (flat on bed). In the Bambu projects it is plate **18 OPTIONAL Dust shoe** (`dust_shoe_52`).
2. Slip the shoe onto the spindle body **below** the lower spindle clamp (remove the endmill / ER nut if needed).
3. Close the clamp slot with **2× M4** through the ears (hose-clamp style).
4. Push a ~ø35 vacuum hose onto the **upward** stub. For ø32 hoses, use a short reducer sleeve.
5. Air path is continuous: bit chamber → plenum → hose (no separate elbow).

## Optional: endstop mounts

Print `endstop_mount_2020` ×4 and optional `endstop_flag` ×0–4 (only if the ~10 mm lever cannot reach a moving face).

### How the mount attaches to 2020 V-slot

Flat plate only — no cradle/frame around the switch:

1. Slide an **M5 T-nut** into the T-slot.
2. Seat the printed **key** into the same slot.
3. From the outside, **M5×12** through the **single ø9.4 recess** (9.2 mm head) into the T-nut.
4. Screw the bare microswitch flat onto the plate with **2× M2** (ø2.0 holes, ~6.5 mm pitch). Pins and lever stay free in air.

### Placement (no holes in aluminium)

1. **Y-L / Y-R** (dual-Y squaring): outer face of each upper side 380 near the rear (Y motors).
2. **X home**: rear face of the bridge near the X motor.
3. **Z home (up)**: front face of a Z column just under the motor tower.

With only three switches: fit **Y-L + Y-R + Z** first.

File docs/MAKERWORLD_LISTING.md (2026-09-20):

# MakerWorld listing draft — MK CNC (WIP)

## Title
MK CNC — scavenger gantry mill from leftover 3D-printer parts (WIP)

## Summary
Small DIY gantry CNC from retired printer leftovers (2020, MGN12, T8, NEMA). Printable interfaces, BOM, assembly docs. Envelope ~299×271×100 mm. Work in progress — expect changes.

## Description
⚠️ Work in progress / early release

This project is still under active development. Parts, fits, docs, and print projects may change. Something may not fit perfectly on your leftover hardware, and dimensions or STLs can be updated without notice. Build at your own risk and expect to tweak.

What it is
A documented scavenger gantry mill: turn leftover 3D-printer parts into a useful small CNC for wood, soft plastics, and light aluminium (conservative feeds). Not a commercial kit and not a cast-iron machine.

What you get
- Printable parts (STL, print orientation)
- Bambu Studio multi-plate projects for P1S and A1 mini
- BOM, printing guide, assembly, overview renders
- Licence: CERN-OHL-P-2.0

Quick specs
- Envelope (nominal): X 299 × Y 271 × Z 100 mm
- Stack: 2020 extrusion + MGN12 + T8 + NEMA steppers
- Default tool: ø52 mm ~500 W spindle (ER11); optional Makita / laser / pen / dust shoe

Credits: misiek1205

Full docs: https://github.com/misiek1205/mk-cnc-build

## Tags (suggested)
cnc, diy, gantry, 3d-printer-parts, scavenger, bambu, p1s, a1-mini, mgn12, 2020, open-hardware

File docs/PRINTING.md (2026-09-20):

# Printing guide

All files in `stl/` are already oriented for printing. **Do not rotate** them in the slicer.  
**No supports** are required when printed as oriented.

`L` / `R` = left / right from the operator (front = spindle).

Preview sheet: [img/parts_print_sheet.png](img/parts_print_sheet.png)

## Shared slicer settings

| Setting | Value |
|---|---|
| Material | **PLA**, **PETG**, or **ASA** — all fine for this machine when printed as below. Reference build used **Bambu Basic PLA**. PETG/ASA if you want more heat resistance or less creep. |
| Nozzle | 0.4 mm |
| Layer height | 0.2 mm |
| Perimeters | **6** (~2.4 mm shell) |
| Top / bottom | **5** layers |
| Infill | **Adaptive Cubic** (or similar) |
| Elephant foot / negative horiz. expansion | Keep bearing seats dimensional |
| Supports | **Off** |

Do **not** print at 100% infill. With 6 perimeters, thin ribs are already nearly solid.

## Part list

| STL | Qty | On bed | Infill | Notes |
|-----|-----|---|---|---|
| `leg_L.stl` / `leg_R.stl` | 1+1 | Outer wall | 40% | Beam pocket opens sideways |
| `leg_cap_L.stl` / `leg_cap_R.stl` | 1+1 | Flat | 40% | |
| `y_motor_bracket_L.stl` / `y_motor_bracket_R.stl` | 1+1 | Motor plate | 40% | Ribs up |
| `y_bearing_block_L.stl` / `y_bearing_block_R.stl` | 1+1 | Tab with M5 | 40% | 608 bore horizontal |
| `side_tie_plate.stl` | 12 | Flat | 40% | |
| `x_motor_bracket.stl` | 1 | Motor plate | 40% | Ribs + wedge up |
| `x_bearing_block.stl` | 1 | Bearing plate | 40% | 608 pocket opens up |
| `x_carriage.stl` | 1 | Side (+X face) | 40% | Height ~105 mm; C-channel sideways |
| `x_nut_block.stl` | 1 | Face toward carriage | 50% | |
| `z_plate.stl` | 1 | Back face | 50% | |
| `z_motor_tower.stl` | 1 | Motor plate | 40% | Collars up; **side T-slots free** |
| `spindle_holder_52.stl` | 1 | Base back | 50% | Default tool |
| `spindle_clamp_cap.stl` | 2 | Flat | 50% | |
| `makita_holder_65.stl` | 0–1 | Optional | 50% | |
| `makita_clamp_cap.stl` | 0–2 | Optional | 50% | |
| `laser_adapter.stl` | 0–1 | Optional | 30% | Nut channels on bed |
| `pen_holder.stl` | 0–1 | Optional | 30% | |
| `dust_shoe_52.stl` | 1 | Flat on bed | 40% | Optional; ø52; clamp slot + 2× M4; upward ø35 hose |

Individual previews: `docs/img/part_<name>.png`.

## Bambu Studio projects

- `bambu/MK_CNC_P1S.3mf` — **18 named plates**, max 2 parts each (side ties share plate 03). Plates **01–13** = required build order; **14–18 OPTIONAL** = Makita / laser / pen / dust shoe.
- `bambu/MK_CNC_A1_mini.3mf` — **21 named plates** (smaller bed splits some pairs). Same stage names; dust shoe is a single optional plate.
- Settings: 0.2 mm, 6 walls, gyroid-style sparse, PLA Basic, supports off.
- Keep the stage names; skip plates whose title starts with **OPTIONAL** if you do not need those tools.

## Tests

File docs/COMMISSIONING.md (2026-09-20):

# Commissioning and safety minimum

This build pack covers the mechanical machine. Do not run the machine until
the following minimum checks have been completed.

## Required before a first powered move

- Fit an accessible emergency stop that removes power from the spindle and
  motion system. A software stop alone is not an emergency stop.
- Fit normally-closed limit switches at both ends of X and Z, and one at each
  Y home position. The two Y motors must be homed independently so the gantry
  can square itself on every homing cycle.
- Configure and test the correct travel limits, homing direction and soft
  limits with the spindle disconnected.
- Bond exposed conductive machine parts and the spindle body to protective
  earth. Provide strain relief for the spindle and drag-chain cables.
- Jog each axis through its full usable travel at low speed. Check that the
  screw, coupler, nut, carriage and cable path cannot contact the frame,
  table or workpiece at either limit.

## Mechanical setup

1. With the machine unpowered, loosen one rail of each parallel rail pair,
   move the carriage through its travel, then tighten progressively. It must
   move freely without a cyclic tight spot.
2. Home Y and measure the gantry-to-frame distance on both sides. Repeat after
   several power cycles; a changing measurement means the two Y drives are not
   being squared reliably.
3. Set the table height and workholding so the installed tool can reach the
   spoilboard without the Z plate, collet nut, dust shoe or motor tower reaching
   a hard stop.
4. Start with wood or plastic and conservative cutting parameters. The printed
   structure and 2020 frame are not intended for aggressive aluminium machining.

## Release check for a published build

- Record the exact cut lengths for every 2020 profile and the rail/screw
  lengths used by the reference machine.
- State the tested controller, the independent-Y homing arrangement and the
  endstop locations.
- Slice every STL with the release slicer profile and resolve any mesh-repair
  warning before publishing the final archive.

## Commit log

2026-09-20 Initial public release: MK CNC scavenger gantry mill build pack.
    STL, docs, Bambu 3MF (P1S / A1 mini), CERN-OHL-P-2.0. Work in progress.
    [MK_CNC_A1_mini.3mf, MK_CNC_P1S.3mf, dust_shoe_52.stl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]
2026-09-20 fix(stl): dust_shoe_52 open vacuum chimney
    Synced from mk-cnc after roof-pierce vacuum clear so the hose tunnel
    is hollow end-to-end in the slice.
    [dust_shoe_52.stl]
2026-09-22 feat: Anet A6 endstop mount STLs and assembly notes
    [endstop_flag.stl, endstop_mount_2020.stl]
2026-09-22 docs: generic endstop mount notes
2026-09-22 fix(stl): bare microswitch endstop mount
    [endstop_mount_2020.stl]
2026-09-22 fix(endstops): open cradle mount; document M5 above switch
    [endstop_mount_2020.stl]
2026-09-22 fix(endstops): 9.2mm head recess and thicker walls
    [endstop_mount_2020.stl]
2026-09-22 fix(endstops): compact mount (24x16x14)
    [endstop_mount_2020.stl]
2026-09-22 fix(endstops): shortened solid cradle, M5 above (22x16x24)
    [endstop_mount_2020.stl]
2026-09-22 fix(endstops): flat plate mount without cradle
    [endstop_mount_2020.stl]
2026-09-22 docs: mark mk-cnc-build as the single public pack
    Parametric CAD stays local; no separate public development repo.
